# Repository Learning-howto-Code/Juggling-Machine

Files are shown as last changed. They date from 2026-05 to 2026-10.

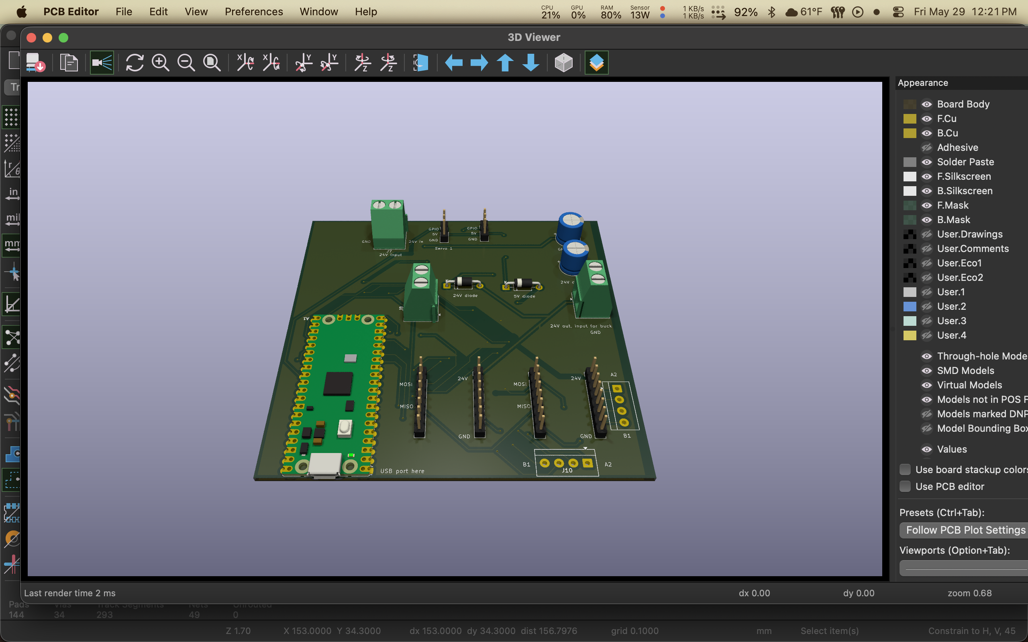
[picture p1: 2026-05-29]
images/Screenshot 2026-05-29 at 12.21.20 PM.png

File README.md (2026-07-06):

# Juggling-Machine
An automatic juggling machine, using a rpi pico, 2 nema 23 stepper motors and some python!

# PCB
Screenshot 2026-05-21 at 7 32 03 PM
Screenshot 2026-05-21 at 7 32 31 PM

# CAD

Screenshot 2026-05-21 at 7 58 25 PM

### Check out the video of the render here!
https://cdn.hackclub.com/019e38e4-be2f-7099-8626-64a2c3647a4a/juggling_machine_video.mp4

# Code
The main code is in main.py, with test scripts to make sure that each part is working first also inlcuded. I am not claiming credit for these, as they are opensource example code

# Bill of Materials

| Item | Unit Cost | Qty | Shipping | Full Cost | Link | Notes |
|---|---|-----|---|---|---|---|
| Stepper Motor | $17.80 | 2 | $16.50 | $54.20 | [NEMA 23 Bipolar](https://www.omc-stepperonline.com/nema-23-bipolar-1-8deg-1-26nm-178-4oz-in-2-8a-2-5v-57x57x56mm-4-wires-23hs22-2804s) | |
| Servo | N/A | 2 | $0.00 | $0.99 | [AliExpress](https://www.aliexpress.us/item/3256808303872992.html) | |
| 2020 Extrusion | 7 | 2 | $3.00 | $14 | [Aliexpress](https://www.aliexpress.us/item/3256803113028246.html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) | |
| Motor Driver | N/A | 2 pack | $6.00 | $42.00 | [TMC5160 Pro v1.0](https://biqu.equipment/products/tmc5160-pro-v1-0?variant=40301980614754) | |
| Screws | N/A | — | — | — | — | Already have |
| RPi Pico | $5.00 | 1 | $12.00 | $11.00 | [LCSC](https://www.lcsc.com/product-detail/C41407547.html) | |
| Capacitor | $0.25 | 2 | — | $0.45 | [LCSC](https://www.lcsc.com/product-detail/C233122.html) | |
| Buck Converter | — | 1 | — | — | — | Already have |
| PCB | $4.00 | 1 | $3.00 | $7.50 | [JLCPCB](https://cart.jlcpcb.com/shopcart/cart/) | |
| | | | **Total** | **$134** | | |

*Claude formatted my BOM*

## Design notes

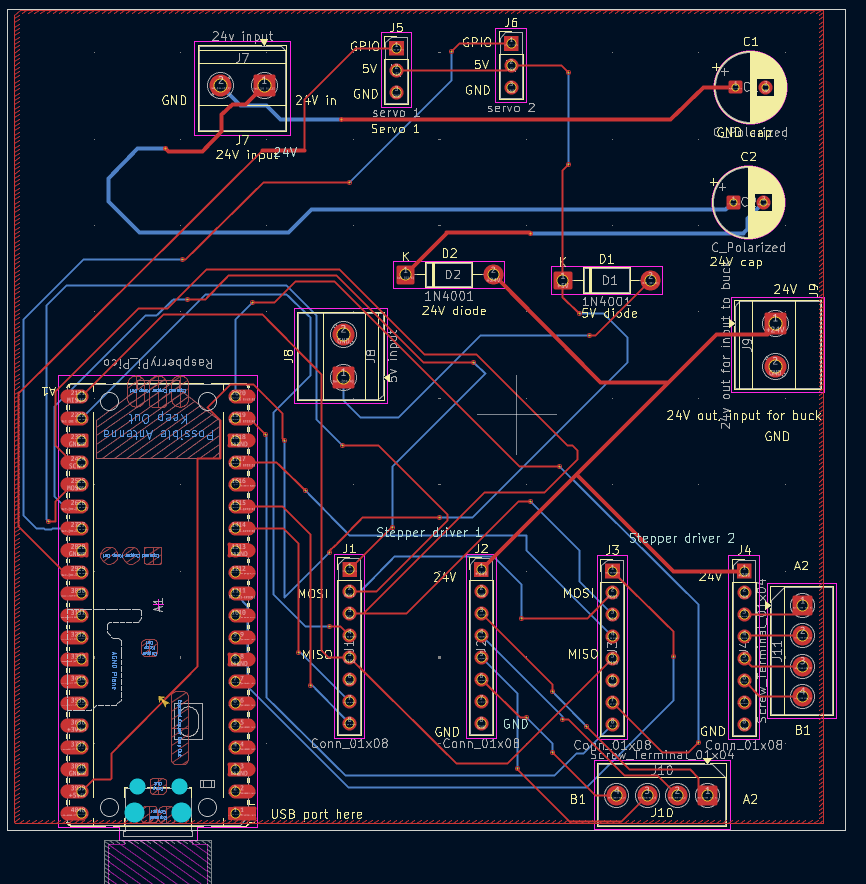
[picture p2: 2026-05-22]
images/Screenshot 2026-05-21 at 7.32.03 PM.png

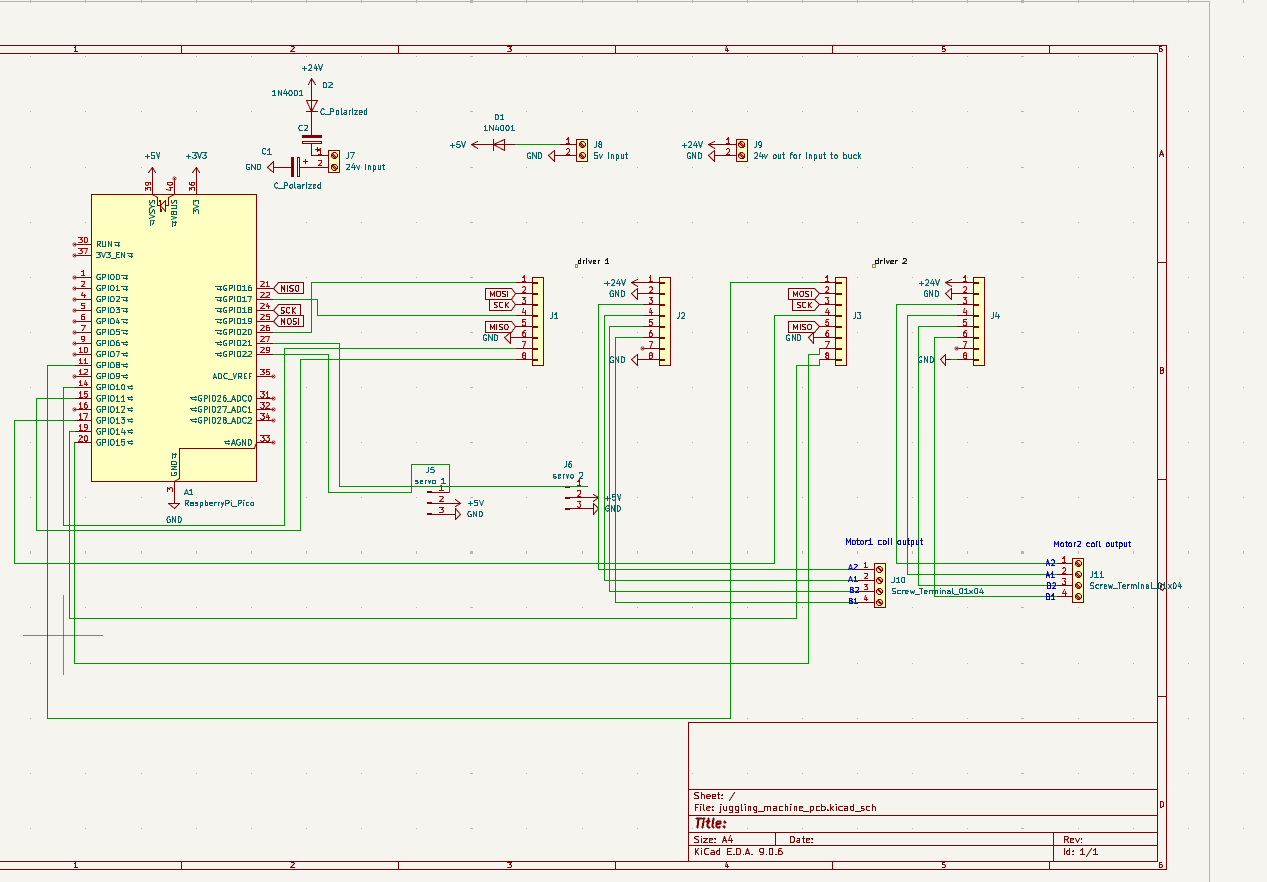
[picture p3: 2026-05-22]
images/Screenshot 2026-05-21 at 7.32.31 PM.png

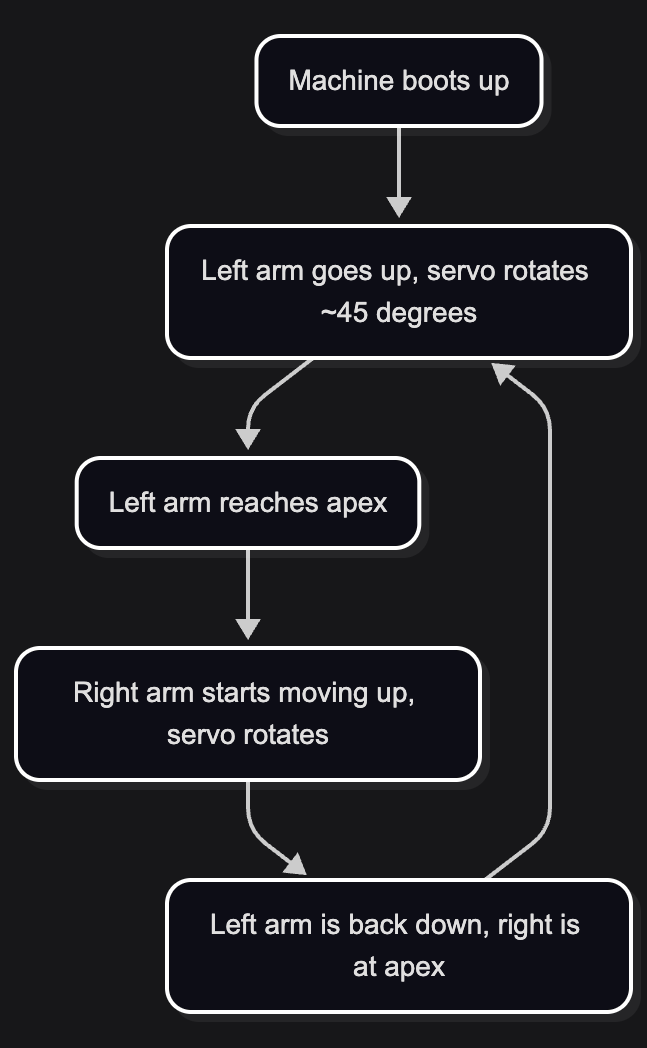
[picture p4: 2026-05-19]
code/flowchart.png

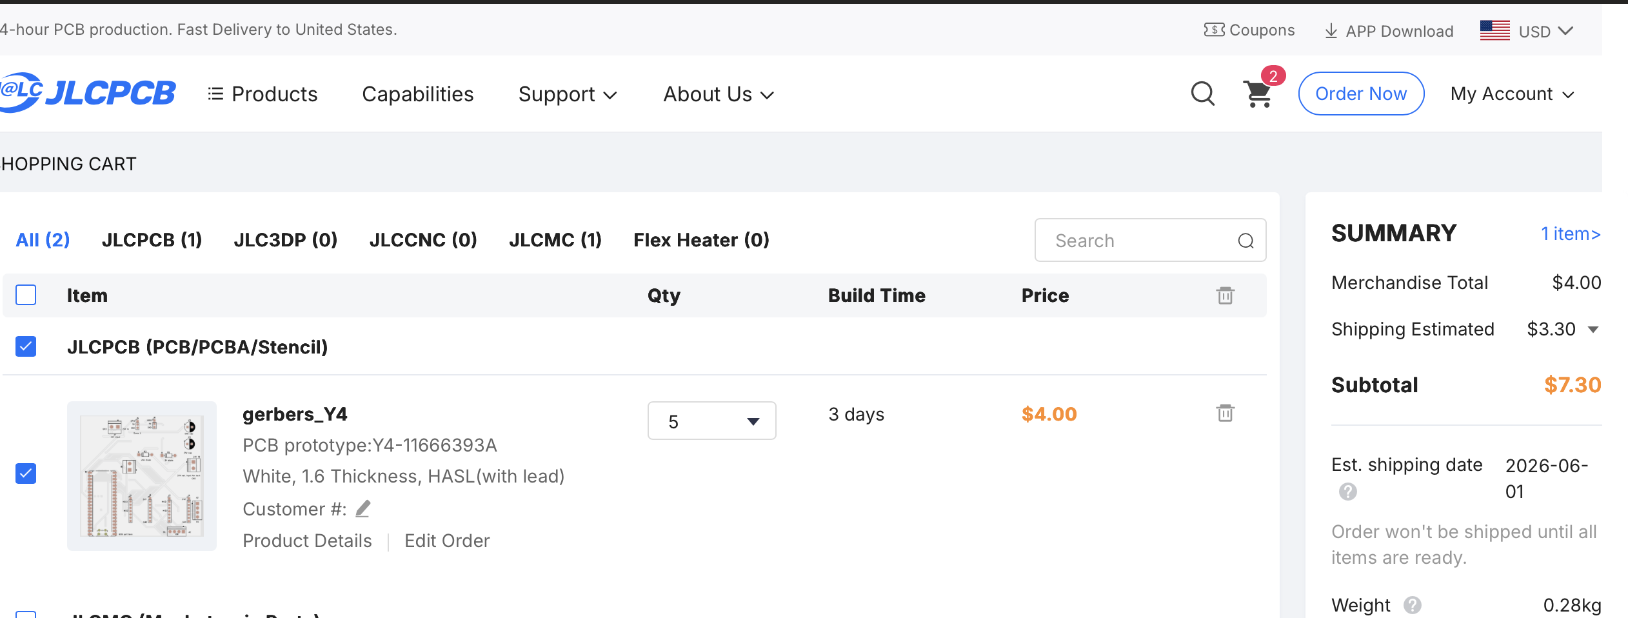
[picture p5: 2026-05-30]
cart_img's/Screenshot 2026-05-29 at 12.49.04 PM.png

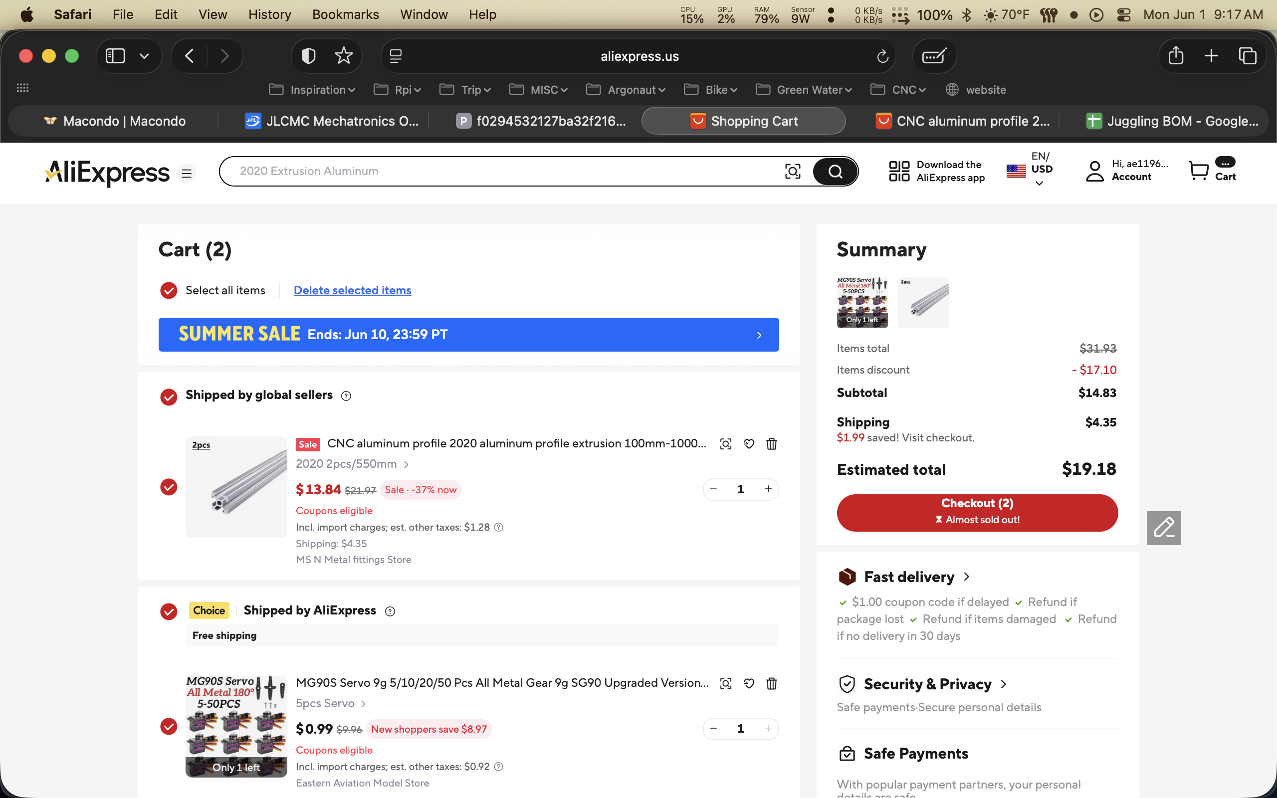
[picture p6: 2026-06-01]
cart_img's/Screenshot 2026-06-01 at 9.17.10 AM.png

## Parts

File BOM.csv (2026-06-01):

Item name | unit cost | quantity | shipping | full cost | link | use/notes
Stepper Motor | $17.80 | 2 | $16.50 | $54.20 | https://www.omc-stepperonline.com/nema-23-bipolar-1-8deg-1-26nm-178-4oz-in-2-8a-2-5v-57x57x56mm-4-wires-23hs22-2804s
Servo | N/A | 2 | $0.00 | $0.99 | https://www.aliexpress.us/item/3256808303872992.html?mp=1
2020 extrusion | $13.00 | 2 | $4.00 | $10.00 | https://www.aliexpress.us/item/3256803113028246.html?curPageLogUid=lDMGDjOTO7JF
Motor Driver | NA | 2 pack | $6.00 | $42.00 | https://biqu.equipment/products/tmc5160-pro-v1-0?variant=40301980614754
Screws | NA |  |  |  | I have these | I got them already
rpi pico | $5.00 | 1 | $12.00 | $11.00 | https://www.lcsc.com/product-detail/C41407547.html
capacitor | $0.25 | 2 |  | $0.45 | https://www.lcsc.com/product-detail/C233122.html?s_z=n_q_t_electrolytic%2520capacitor%2520
buck converter |  | 1 |  |  |  | I already have this
PCB | $4.00 | 1 | $3.00 | $7.50 | https://cart.jlcpcb.com/shopcart/cart/ | Not sure how to link the quote page
 |  |  |  | $130.00

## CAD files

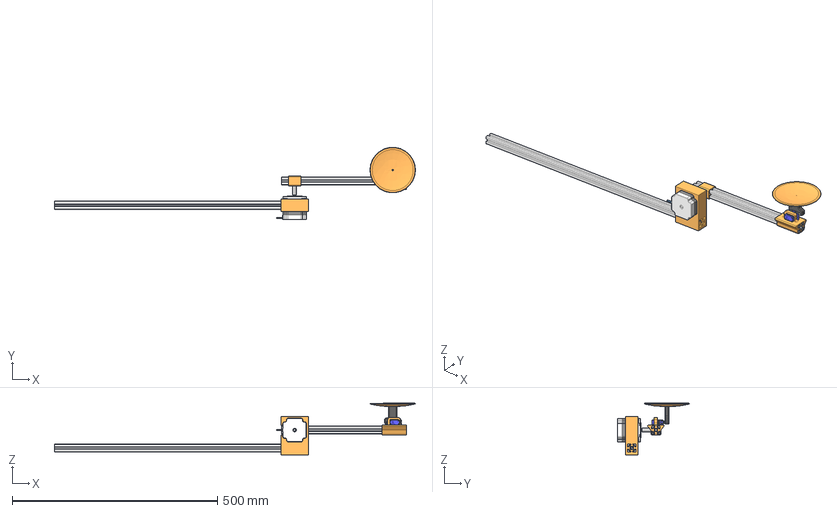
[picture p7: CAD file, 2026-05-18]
CAD/juggling machine.step
879.8 x 175.8 x 125.6 mm
5537T501_T-Slotted Framing
arm mount
23HS22-2804S
mount
SG90 - Micro Servo 9g - Tower Pro.1_Pea
SG90 - Micro Servo 9g - Tower Pro.3_Pea
nema mount
5537T104_T-Slotted Framing

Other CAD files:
CAD/juggling machine.f3z
CAD/juggling machine.stl

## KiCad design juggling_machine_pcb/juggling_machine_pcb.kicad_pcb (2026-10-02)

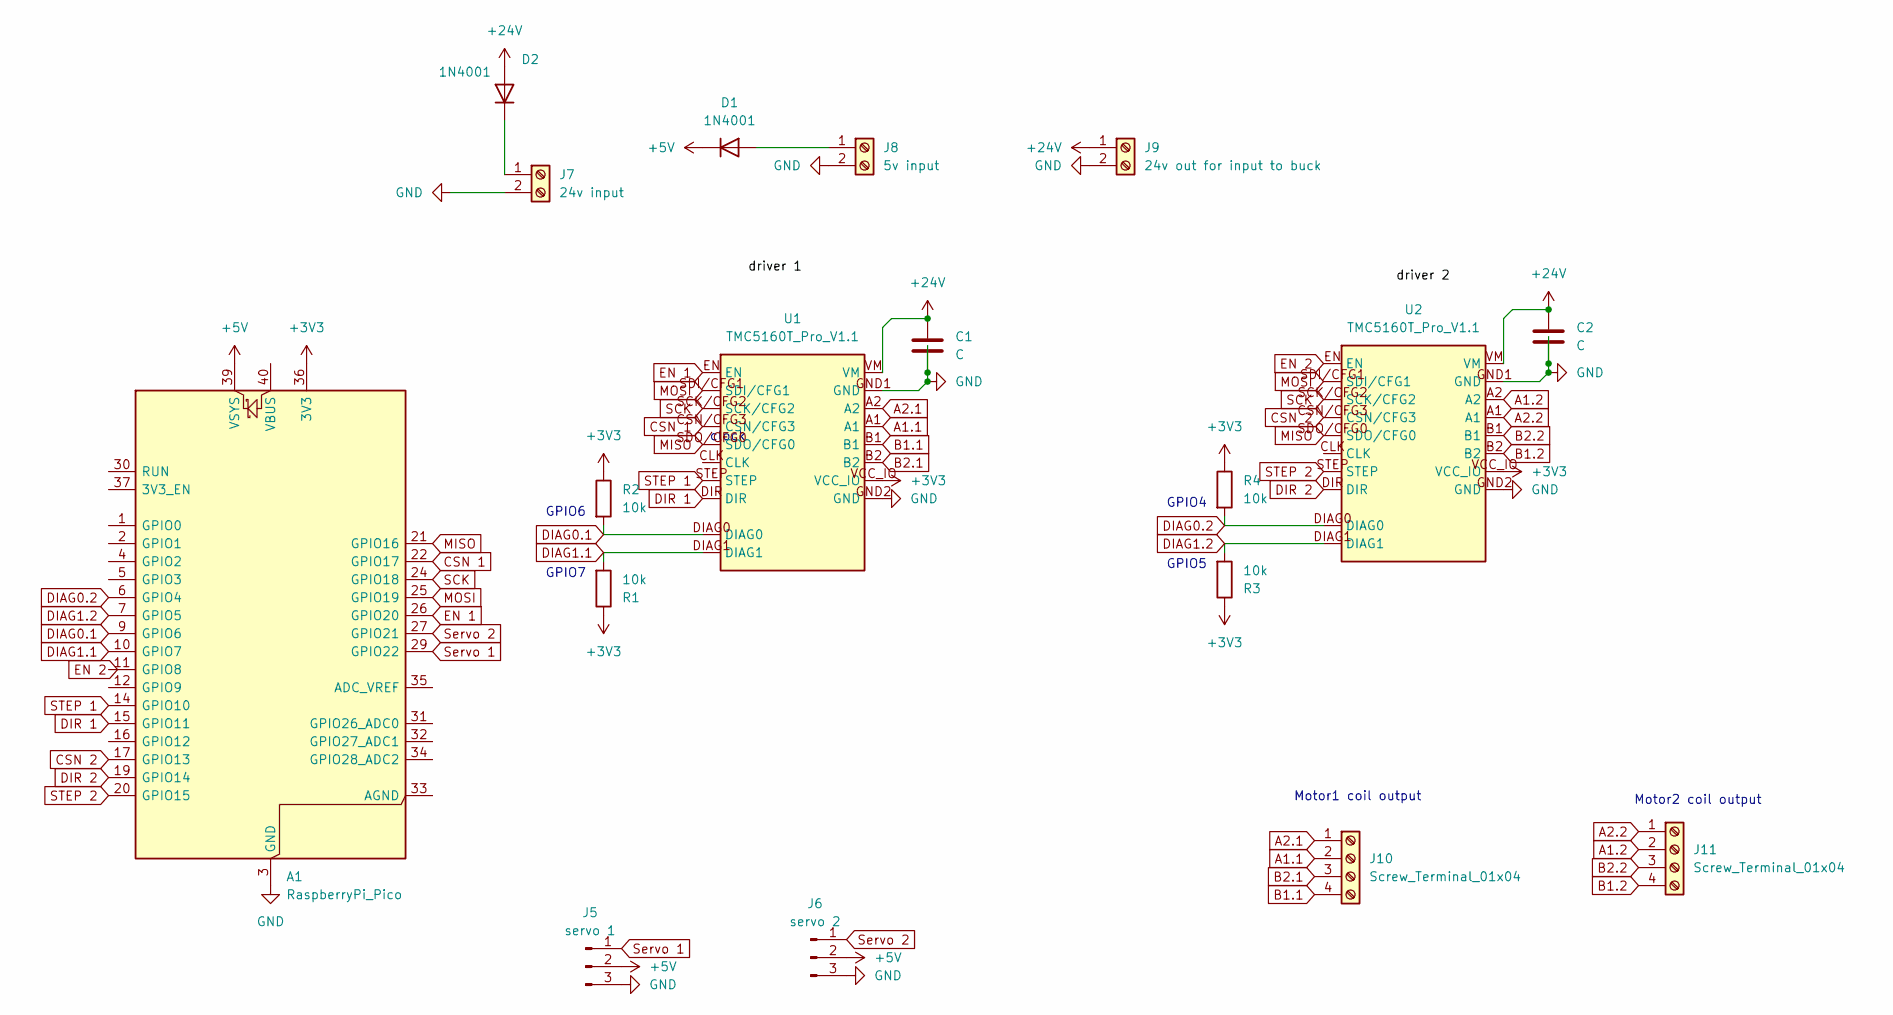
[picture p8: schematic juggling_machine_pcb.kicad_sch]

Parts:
A1: RaspberryPi_Pico; RaspberryPi_Pico_Common_Unspecified
C1, C2: C; CP_Radial_D6.3mm_P2.50mm
D1, D2: 1N4001; D_DO-41_SOD81_P10.16mm_Horizontal
J5: servo 1; PinHeader_1x03_P2.54mm_Vertical
J6: servo 2; PinHeader_1x03_P2.54mm_Vertical
J7: 24v input; TerminalBlock_Phoenix_MKDS-1,5-2_1x02_P5.00mm_Horizontal
J8: 5v input; TerminalBlock_Phoenix_MKDS-1,5-2_1x02_P5.00mm_Horizontal
J9: 24v out for input to buck; TerminalBlock_Phoenix_MKDS-1,5-2_1x02_P5.00mm_Horizontal
J10, J11: Screw_Terminal_01x04; TerminalBlock_4Ucon_1x04_P3.50mm_Horizontal
R1, R2, R3, R4: 10k; R_Axial_DIN0204_L3.6mm_D1.6mm_P5.08mm_Horizontal
U1, U2: TMC5160T_Pro_V1.1; BTT_TMC5160T_Pro_V1.1

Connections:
+3V3: A1.36 (3V3), R1.1, R2.1, R3.1, R4.1, U1.VCC_IO, U2.VCC_IO
+5V: A1.39 (VSYS), D1.1 (K), J5.2, J6.2
+24V: C1.1, C2.1, D2.2 (A), J9.1, U1.VM, U2.VM
A1.1: J10.2, U1.A1
A1.2: J11.2, U2.A2
A2.1: J10.1, U1.A2
A2.2: J11.1, U2.A1
B1.1: J10.4, U1.B1
B1.2: J11.4, U2.B2
B2.1: J10.3, U1.B2
B2.2: J11.3, U2.B1
CSN 1: A1.22 (GPIO17), U1.CSN/CFG3
CSN 2: A1.17 (GPIO13), U2.CSN/CFG3
DIAG0.1: A1.9 (GPIO6), R2.2, U1.DIAG0
DIAG0.2: A1.6 (GPIO4), R4.2, U2.DIAG0
DIAG1.1: A1.10 (GPIO7), R1.2, U1.DIAG1
DIAG1.2: A1.7 (GPIO5), R3.2, U2.DIAG1
DIR 1: A1.15 (GPIO11), U1.DIR
DIR 2: A1.19 (GPIO14), U2.DIR
EN 1: A1.26 (GPIO20), U1.EN
EN 2: U2.EN
GND: A1.3 (GND), A1.8 (GND), A1.13 (GND), A1.18 (GND), A1.23 (GND), A1.28 (GND), A1.38 (GND), C1.2, C2.2, J5.3, J6.3, J7.2, J8.2, J9.2, U1.GND1 (GND), U1.GND2 (GND), U2.GND1 (GND), U2.GND2 (GND)
MISO: A1.21 (GPIO16), U1.SDO/CFG0, U2.SDO/CFG0
MOSI: A1.25 (GPIO19), U1.SDI/CFG1, U2.SDI/CFG1
unnamed: D1.2 (A), J8.1
unnamed: D2.1 (K), J7.1
SCK: A1.24 (GPIO18), U1.SCK/CFG2, U2.SCK/CFG2
STEP 1: A1.14 (GPIO10), U1.STEP
STEP 2: A1.20 (GPIO15), U2.STEP
Servo 1: A1.29 (GPIO22), J5.1
Servo 2: A1.27 (GPIO21), J6.1

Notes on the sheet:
clock
Motor2 coil output
GPIO4
GPIO6
GPIO7
GPIO5
Motor1 coil output

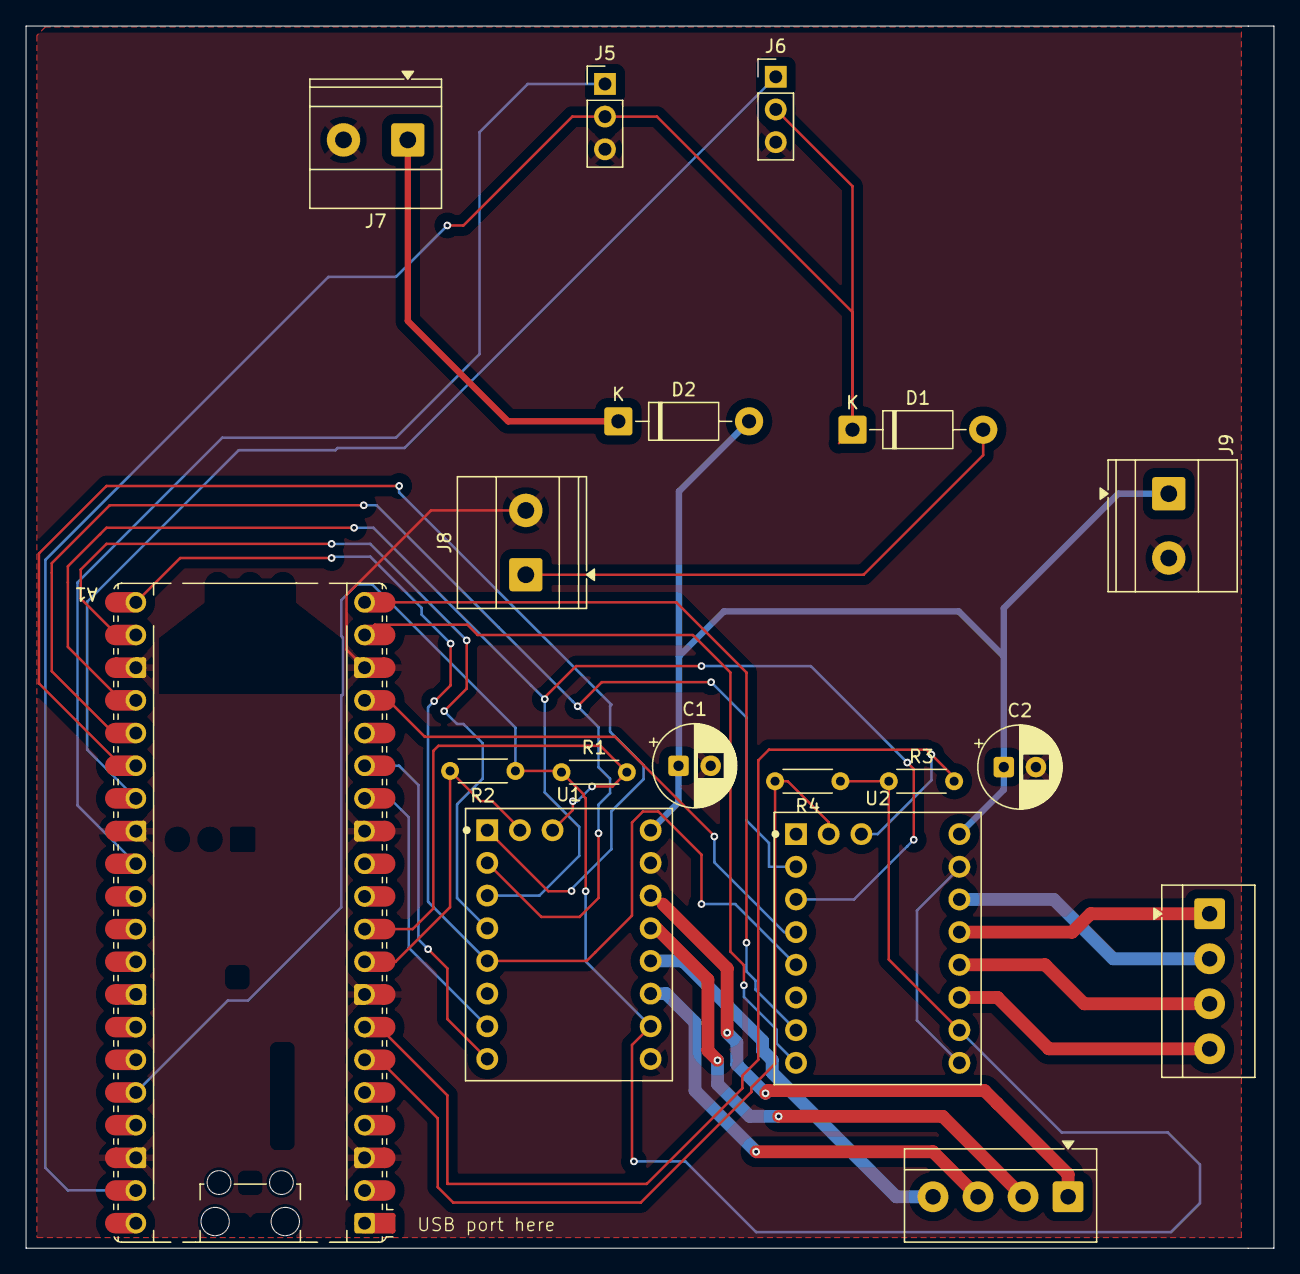
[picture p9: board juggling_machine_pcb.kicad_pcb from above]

Board: 2 copper layers, 97.0 x 95.0 mm, 18 parts (0 on the bottom side), 30 nets.

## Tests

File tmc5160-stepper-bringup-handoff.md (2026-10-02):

# Juggling Machine TMC5160 Stepper Bring-up — Context Handoff
*Compacted 2026-09-29 · ~20 turns, covering the rewrite of the stepper test script, the EN 2 PCB bug, coil-wiring fault debugging, and the two-motor test*

## Objective
Get the two NEMA 23 stepper motors on the juggling machine turning under MicroPython on a Raspberry Pi Pico 2 (RP2350). Each motor is driven by a BIGTREETECH TMC5160T Pro V1.0 driver on the custom PCB (`juggling_machine_pcb`). `code/test_stepper.py` is the bench test that spins the motors slowly. The machine's main code still has to be written: `code/main.py` is currently broken.

## Current State
- `code/test_stepper.py` **works on real hardware**. It configures both drivers over SPI and jogs both motors together: 1 revolution forward, a 1 s pause, then 1 revolution back, at `RPM = 10`.
  - It was confirmed working on driver 1 earlier.
  - The two-motor version was tested **only in a CPython simulation** (mocked `machine` module). It hasn't been run on the Pico yet.
- **EN 2 PCB bug** is worked around with a jumper wire from U2 EN to Pico pin 11 (GP8). The script's EN check has since passed for driver 2.
- **Coil B fault (`s2vsb=1`, `olb=1`, `drv_err=1`)** on driver 1 was fixed by the user rearranging motor wires in the screw terminal. The correct wire/colour order was **not recorded**.
- Driver 2's coil B fault and its later "no response" state are **not confirmed resolved** (see Open Questions).
- `code/main.py` is untouched and broken.

## Key Facts & Values

### Hardware
| Item | Value | Notes |
|---|---|---|
| MCU | Raspberry Pi Pico 2 (RP2350) | MicroPython (the old code was CircuitPython) |
| Driver | BIGTREETECH TMC5160T Pro V1.0 (chip TMC5160-TA) | KiCad footprint is named `BTT_TMC5160T_Pro_V1.1` |
| Sense resistor | 0.075 Ω | 3.1 A RMS / 4.4 A peak max (BTT manual) |
| SD_MODE / SPI_MODE | both tied to VCC_IO via 0 Ω (R7, R6) on module | → **STEP/DIR mode only**; SPI only configures. Internal ramp generator unusable |
| Module CLK | tied to GND via 10K (R4) | internal 12 MHz clock |
| Motor | StepperOnline 23HS22-2804S | 2.8 A rated, 1.26 Nm, ~1 Ω/phase ("~1 Ω" used in checks) |
| VM | +24 V | TMC5160 logic is powered from VM. **VM must be on** or SPI reads 0 or all-ones |
| VCC_IO | +3V3 from Pico | |
| DIAG pull-ups | 10k to 3V3 (R1–R4) | DIAG0 is open drain, active low |

### Pico pin map (from PCB netlist)
| Signal | Driver 1 (U1) | Driver 2 (U2) |
|---|---|---|
| EN (active low) | GPIO20 | GPIO8 (**jumper wire**; not routed on PCB) |
| CSN | GPIO17 | GPIO13 |
| STEP | GPIO10 | GPIO15 |
| DIR | GPIO11 | GPIO14 |
| DIAG0 | GPIO6 | GPIO4 |
| DIAG1 | GPIO7 | GPIO5 |
| Shared SPI0 | SCK GPIO18, MOSI GPIO19, MISO GPIO16 | same |
| Servos | Servo 1 GPIO22, Servo 2 GPIO21 | |

- Pico physical pin 11 = GP8. Pins 8 and 13 are GND. Pins 9/10 = GP6/GP7, which carry driver 1's DIAG with 10k pull-ups.
- Motor terminals: J10 (driver 1) and J11 (driver 2). **Pins 1–2 = coil A, pins 3–4 = coil B.**
  - J10: pin1→U1 A2, pin2→U1 A1, pin3→U1 B2, pin4→U1 B1.
  - J11: pin1→U2 A1, pin2→U2 A2, pin3→U2 B1, pin4→U2 B2.

### PCB findings
- **EN 2 bug:** schematic global label "EN 2" near the Pico is at x=46.99, while neighbouring labels (CSN 2, DIR 2, STEP 2) are at x=45.72. The label is dangling, so the net EN 2 has only 1 pad (U2 EN) and 0 traces. The PCB lists `unconnected-(A1-GPIO8-Pad11)`.
- All other nets are routed. `kicad-cli pcb drc` on the current `juggling_machine_pcb.kicad_pcb` gives 0 violations and 0 unconnected. `kicad-cli` is at `/Applications/KiCad/KiCad.app/Contents/MacOS/kicad-cli`.
- Pad coordinates (mm): U2 EN (109.85, 87.81); Pico pad 11 (77.11, 92.66), about 33 mm apart. U2 B2 (122.55, 100.51) sits next to U2 VCC_IO (122.55, 103.05). The nearest GND pads to U2 EN (C1 pad 2, U2 GND1) are each next to a +24 V pad.

### Driver configuration used in the script
| Register | Value | Meaning |
|---|---|---|
| GCONF 0x00 | read-modify-write `\| (1<<5)` | diag0_error; result 0x28 with the default multistep_filt |
| CHOPCONF 0x6C | `0x140100C3` | TOFF=3, HSTRT=4, HEND=1, TBL=2, SpreadCycle, MRES=4 (16 µsteps), intpol=1 |
| GLOBALSCALER 0x0B | 67 (0x43) | for 0.8 A RMS |
| IHOLD_IRUN 0x10 | `0x00061F0F` | IRUN=31, IHOLD=15, IHOLDDELAY=6 → 0.8 A run / 0.4 A hold |
| TPOWERDOWN 0x11 | 10 | |
| GSTAT 0x01 | write `0b111` to clear | |
| IOIN 0x04 | VERSION bits 31..24 = 0x30; bit4 DRV_ENN; bit6 SD_MODE | used for the chip-present and EN-reaching-driver checks |

- SPI: mode 3 (polarity=1, phase=1), 1 MHz, 40-bit datagrams, write = addr|0x80. A read returns its data on the **next** datagram.
- Current formula: `I_rms = GLOBALSCALER/256 * (CS+1)/32 * VFS/RSENSE / sqrt(2)`, with VFS = 0.325 V. GLOBALSCALER 1–31 is not allowed; 256 is written as 0.

### DRV_STATUS (0x6F) bits
| Bit | Name | Meaning |
|---|---|---|
| 0–9 | SG_RESULT | stallGuard result |
| 12 | s2vsa | short to supply, coil A |
| 13 | s2vsb | short to supply, coil B |
| 16–20 | CS_ACTUAL | actual current scale |
| 25 | ot | overtemperature |
| 26 | otpw | overtemperature pre-warning |
| 27 | s2ga | short to GND, coil A |
| 28 | s2gb | short to GND, coil B |
| 29 | ola | open load, coil A |
| 30 | olb | open load, coil B |
| 31 | stst | standstill |

GSTAT bits: 0 = reset, 1 = drv_err, 2 = uv_cp.

### Observed fault signatures
| Output | Meaning |
|---|---|
| `drv_err=1`, `s2vsb=1`, `olb=1`, `DRV_STATUS 0x411f2000`, trips after 0–9 steps | Coil pairs mixed across the terminal (fixed on driver 1 by rewiring) |
| `DRV_STATUS 0x800f23ff`, `s2vsb=1` | Same fault on driver 2 |
| `IOIN=0xffffffff`, all status bits 1 | Nothing answering on SPI: VM off, a dead module, or a module pulling down the shared MISO line |
| `IOIN=0x00000000` | No VM, or chip not seated |
| `Driver still sees EN high` | EN wire not reaching the driver (hit on driver 2 before the jumper was fixed) |

## Decisions Made
- **Raw SPI register code, no library.** `tmc_driver` / pytmcstepper (in `code/venv`) is CircuitPython/Linux-only and targets TMC2209 over UART.
- **STEP/DIR motion from Pico GPIO.** SD_MODE is hard-wired to 1 on the module, so the internal ramp generator can't drive the motor. The user's original pin list omitted STEP; GPIO15/GPIO10 came from the PCB netlist.
- **SpreadCycle, not StealthChop.** It needs no auto-tuning, so it's more robust for first spin.
- **0.8 A run / 0.4 A hold**, deliberately low for the bench (motor is rated 2.8 A).
- **16 microsteps with interpolation to 256**, for smooth slow motion.
- **Status is read before disabling EN.** Disabling clears the fault flags, which hid them on the first driver 2 fault.
- **Wire-order HINT prints only when `drv_err=1` and (s2vsa|s2vsb|ola|olb)**, because ola/olb can false-trigger at standstill after a normal run.
- **EN 2 workaround = jumper U2 EN → Pico pin 11 (GP8)**, so the code keeps using GPIO8. The user chose and did this.
- **Both drivers share one step loop.** Both STEP pins are pulsed in the same pass, and a DIAG0-low on either driver stops both. Driver objects are created before any SPI traffic so all CSNs are high.

## Ruled Out
- **Using the TMC5160 internal ramp generator (RAMPMODE/XTARGET)** — SD_MODE=1 is hard-wired on the BTT module.
- **`tmc_driver` Tmc2209 / CircuitPython `board` code** — wrong chip, wrong bus, wrong firmware.
- **Leaving EN 2 floating** — DRV_ENN pull behaviour is unconfirmed, and a floating input is unreliable near motor wiring.
- **PCB design short on coil B** — DRC is clean. The fault was the motor wire order at the terminal.
- **Speed as the cause of the coil B fault** — it tripped at 0–9 steps at 10–12 RPM too.

## Artifacts
- `code/test_stepper.py` — **current, working** two-driver test. It uses the `Driver` class and the `DRIVER_PINS` dict.
- Simulation mocks, in the session scratchpad (temporary, may be gone): `mock2/machine.py` (two-chip TMC5160 SPI mock), `run2.py` (pass any argument to fake a driver 2 coil fault). A clean run gave 6400 step pulses per driver.
- Reference docs used:
  - BTT TMC5160T Pro V1.0 User Manual: `github.com/bigtreetech/BIGTREETECH-Stepper-Motor-Driver/.../TMC5160(T) Pro V1.1/TMC5160T Pro V1.0 User Manual.pdf`
  - Module schematic: `.../TMC5160(T) Pro V1.1/Hardware/BIGTREETECH TMC5160T_Pro-SCH.pdf`
  - BTT docs: `github.com/bigtreetech/docs/blob/master/docs/TMC5160T Pro V1.0.md`

## Code & Config
Current per-driver pin table and core SPI read (in `code/test_stepper.py`):
```python
DRIVER_PINS = {
    1: dict(en=20, csn=17, step=10, dir=11, diag0=6, diag1=7),
    2: dict(en=8, csn=13, step=15, dir=14, diag0=4, diag1=5),
}

def read_reg(self, addr):
    # The TMC5160 answers a read on the following datagram
    self.transfer(addr)
    return self.transfer(addr)[1]
```
Run it with: `cd /Users/jakehopkins/Projects/Juggling-Machine/code && mpremote run test_stepper.py`. `mpremote` is at `~/.local/bin/mpremote`; the MicroPico VS Code extension is also installed.

## Open Questions
- **Is driver 2 healthy now?** It showed the same `s2vsb` coil B fault. A later run returned `IOIN=0xffffffff` (no response). Possible causes: VM supply tripped, the module damaged by repeated shorts, or J11 wiring still mixed. The user never reported fixing J11 or re-testing driver 2 alone. Settle it by running the new two-motor script, or driver 2 alone, after checking J11 pairs with a meter.
- **Were the driver modules swapped between U1 and U2?** Asked, never answered.
- **Correct motor wire colours are unknown.** The assistant's table (black/green = coil A, red/blue = coil B, StepperOnline typical) may be wrong for this motor, since the fix involved changing the wire order. Record the actual working order.
- **Two-motor script not yet run on hardware.**
- **Does Ctrl-C under `mpremote run` stop the script on the device?** Unverified; `mpremote soft-reset` was given as the fallback.
- **Does TMC5160 DRV_ENN have an internal pull resistor?** Not confirmed; the datasheet download failed.
- **Direction:** both motors turn the same way. Mirrored arms may need one reversed (swap one coil's pair, or add per-driver inversion).
- **Which PCB revision was fabricated?** The working tree has modified gerbers and a new `manufacturing.zip`. The DRC result applies to the current file only.

## Next Steps
1. Power off. On J11 (driver 2), verify about 1 Ω across pins 1–2 and across 3–4, open between pairs and open to the motor case. Fix pairing the same way driver 1 was fixed. Record the working colour order.
2. Power the 24 V first, then USB, and run `mpremote run test_stepper.py`. Expect "Driver 1/2: TMC5160 found" and both motors turning 1 rev each way.
3. If driver 2 returns `0xffffffff`: check VM at U2, pull the U2 module (a dead module can pull down the shared MISO line), and test driver 1 alone by temporarily removing key `2` from `DRIVER_PINS`.
4. Fix the schematic for the next PCB rev: move the "EN 2" label onto the GPIO8 wire at x=45.72, update the PCB from the schematic, route the new trace, and run ERC (it flags dangling labels) before ordering.
5. Build the real motion code for `code/main.py`. It currently imports a nonexistent `tmc.TMC_5160`, uses `threading`, and has no `tmc` object. It needs PIO/timer step generation with acceleration ramps (the Python loop can't go much past about 60–100 RPM, and there's no ramp) plus the servo PWM from `code/test_servo.py` (50 Hz, 500–2500 µs).

## Working Context
- The user runs code with `mpremote run test_stepper.py` from `code/` (sometimes inside `(venv)`), and pastes terminal output for diagnosis.
- Caveman mode is active for chat replies: terse, articles dropped. Code, comments and commits are written normally.
- Code style follows `code/test_servo.py`: `from machine import Pin, ...  # type: ignore`, sparse comments, `%`-formatting.
- The user edits the script directly (RPM, REVOLUTIONS, pin blocks). Read the file before editing.
- Before telling the user what to rewire, always flag the risks: never hot-plug motors or drivers with 24 V on, and watch for +24 V pads next to GND pads.

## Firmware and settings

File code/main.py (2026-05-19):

from machine import Pin, PWM, machine # type: ignore
from time import sleep, time
import logging
import threading

from tmc.TMC_5160 import  ( # type: ignore
    stopMode,
    Loglevel,
    Board,
    tmc_gpio,
    MovementPhase,
    MovementAbsRel,
    TMC_5160,
    TmcEnableControlPin,
    TmcMotionControlStepDir,
)

range_angle = 120
distance = -((round(range_angle/360)*200))
motor = TMC_5160(
    spi_id=0,
    cs_pin=17,
    sck_pin=18,
    mosi_pin=19,
    miso_pin=16,
    step_pin=2,
    dir_pin=3,
    en_pin=6,
    DIAG0=31
)
servoLeft= machine.Pin(29)
servoRight= machine.Pin(27)
# these functions change settings in the TMC register
# -----------------------------------------------------------------------
tmc.set_direction_reg(False)
tmc.set_current_rms(300)
tmc.set_interpolation(True)
tmc.set_spreadcycle(False)
tmc.set_microstepping_resolution(2)
tmc.set_internal_rsense(False)

# these functions read and print the current settings in the TMC register
tmc.read_register("ioin")
tmc.read_register("chopconf")
tmc.read_register("drvstatus")
tmc.read_register("gconf")

print("---\n---")

# set the Acceleration and maximal Speed in fullsteps
# -----------------------------------------------------------------------
tmc.acceleration_fullstep = 1000
tmc.max_speed_fullstep = 250

# sets up log verbosity, and absolute cords
tmc.tmc_logger.loglevel = Loglevel.DEBUG
tmc.movement_abs_rel = MovementAbsRel.ABSOLUTE
# activate the motor current output
# -----------------------------------------------------------------------
tmc.set_motor_enabled(True)

tmc.test_stallguard_threshold(200) # rotates once

def my_callback():
    """StallGuard callback"""
    print("StallGuard detected!!")
    tmc.tmc_mc.stop()

# 1, pin, threshhold(50 is default), callback funtion, min speed threshold(optional)
tmc.set_stallguard_callback( # will call my_callback when stallguard detected
    26, 50, my_callback
)  # after this function call, StallGuard is active


# uses STEP/DIR to move the motor
result = tmc.run_to_position_steps(4000, MovementAbsRel.RELATIVE)
if result is StopMode.NO:
    print("Movement finished successfully")
else:
    print("Movement was not completed")

# ^^is all setup^^
tmc.set_motor_enabled(True)
def home():
    stopLeft = tmc.do_homing(26, 1, 50)
    positionLeft = tmc.current_pos

    stopRight= tmc.do_homing(27, 1, 50)
    positionRight = tmc.current_pos

servo = PWM(servoLeft)
max_duty = 7864
min_duty = 1802
half_duty = int(max_duty/2)
servo.freq (50)
def moveLeft(): # needs to move clockwise to launch ball
    start = time.time_ns()
    def run_motor():
        tmc.run_to_position_fullsteps(distance)
        tmc.run_to_position_fullsteps(-distance)
    def run_servo():
        servo.duty_u16(half_duty)
        servo.duty_u16(0)
    left_thread_motor = threading.Thread(target=run_motor, name="left_motor_thread")
    left_thread_servo = threading.Thread(target=run_servo, name="left_servo_thread")
    left_thread_motor.start(), left_thread_servo.start() # uses threads so that both can move at the same time
    left_total = time.time_ns() - start
    return left_total
def moveRight():
    start = time.time_ns()
    def run_motor():
        tmc.run_to_position_fullsteps(-distance)
        tmc.run_to_position_fullsteps(distance)
    def run_servo():
        servo.duty_u16(-(half_duty))
        servo.duty_u16(0)
    right_thread_motor = threading.Thread(target=run_motor, name="right_motor_thread")
    right_thread_servo = threading.Thread(target=run_servo, name="right_servo_thread")
    right_thread_motor.start(), right_thread_servo.start() # uses threads so that both can move at the same time    
    end = time.time_ns()
    right_total = end - start
    return right_total

while True:
    left_total = moveLeft()/1_000_000_000 # converts nanoseconds to seconds
    print("left arm run time is {left_total} seconds")
    sleep(left_total/2)
    right_total = moveRight()/1_000_000_000 # converts nanoseconds to seconds
    print("right arm run time is {right_total} seconds")
    sleep(right_total/2)






    

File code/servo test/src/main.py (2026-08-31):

import time

import board
import pwmio
from adafruit_motor import servo

# signal wire on GP22 (physical pin 29)
pwm = pwmio.PWMOut(board.GP22, duty_cycle=0, frequency=50)
my_servo = servo.Servo(pwm)

while True:
    my_servo.angle = 0
    time.sleep(1)
    my_servo.angle = 90
    time.sleep(1)
    my_servo.angle = 180
    time.sleep(1)

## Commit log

2026-05-17 added pcb files, and video from cad render
    [juggling_machine_pcb-B_Cu.gbr, juggling_machine_pcb-B_Mask.gbr, juggling_machine_pcb-B_Paste.gbr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]
2026-05-18 added step, stl, and f3z CAD files from fusion
    [juggling machine.f3z, juggling machine.step, juggling machine.stl]
2026-05-19 worked out full logic for code, also added test scripts for servos and stepper motors
2026-05-22 added bom and updated pcb
    [BOM.csv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]
2026-05-29 added new BOM, plus updated pcb
    [BOM.csv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]
2026-05-30 latest changes
    [juggling_machine_pcb.kicad_pcb]
2026-06-01 updated BOM with new 2020 supplier
2026-06-01 new BOM
    [BOM.csv]
2026-06-15 Fixed typo in bom total.
2026-07-06 updated pcb, added platformio workspace
    [juggling_machine_pcb-B_Cu.gbr, juggling_machine_pcb-B_Mask.gbr, juggling_machine_pcb-B_Paste.gbr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]
2026-08-31 rerouted pcb with new motor driver footprint
    [juggling_machine_pcb.kicad_pcb, juggling_machine_pcb.kicad_sch]
2026-10-02 second revision of pcb
    [juggling_machine_pcb-B_Cu.gbr, juggling_machine_pcb-B_Mask.gbr, juggling_machine_pcb-B_Paste.gbr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]
